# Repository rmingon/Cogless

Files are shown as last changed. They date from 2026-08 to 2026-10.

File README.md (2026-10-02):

<h1 align="center">Cogless</h1>

<p align="center">
  <strong>A single-chip, open-source brushless ESC built around the WCH CH32M007.</strong><br>
  One RISC-V motor-control SoC, six MOSFETs, a handful of passives. Every design file public.
</p>

<p align="center">
  
  
  
  
  
  
  
</p>

<p align="center">
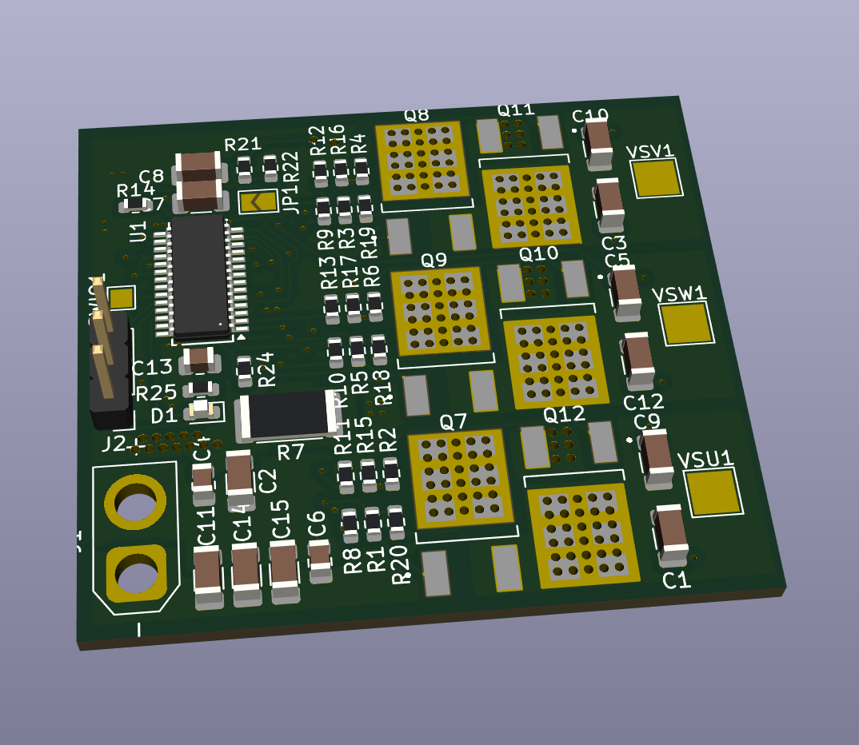
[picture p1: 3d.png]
Cogless 3D render
  
</p>

---

## Overview

Most hobby ESCs are black boxes: closed firmware, undocumented hardware, and a microcontroller, gate driver and op-amps spread over a dozen chips. Cogless takes the opposite approach.

The **WCH CH32M007G8R6** integrates on a single die everything the brain of an ESC needs: a RISC-V core, a three-phase 48 V N+N gate pre-driver with bootstrap diodes, the high-voltage and logic regulators, a programmable-gain current amplifier, comparators wired to the PWM timer's emergency brake, and a 3 Msps ADC. The result is a complete motor controller with **one IC, six MOSFETs and a few passives** on a 45 × 40 mm board.

| | |
|---|---|
| **Control** | Sensorless six-step (trapezoidal) commutation, back-EMF sensing |
| **Start-up** | Automatic motor detection and tuning, stored in flash |
| **Protection** | Hardware over-current break, cycle-by-cycle current limit, voltage and thermal derating |
| **Openness** | KiCad sources, fabrication outputs and firmware, dual-licensed |

## Hardware

### Specifications

| Parameter | Value |
|---|---|
| Controller | WCH CH32M007G8R6, QingKe RISC-V, 48 MHz, 62 KB flash, 8 KB RAM, SSOP-28 |
| Gate driver | Integrated three-phase N+N pre-driver, bootstrap diodes, up to 48 V |
| Power stage | 6 × AOD514 (30 V, 46 A, 5.9 mΩ), DPAK, thermal via arrays |
| Supply | 2S to 4S LiPo (6 V to 16.8 V), XT30 connector |
| Regulation | Internal high-voltage LDO and 5 V logic LDO, no external regulator |
| Current sense | 2 mΩ 2512 shunt, Kelvin-routed differential pair, internal PGA (× 16) |
| Voltage sense | Three phase back-EMF dividers and one battery divider, 33 kΩ / 8.2 kΩ (≈ 25 V full scale) |
| Temperature | 10 kΩ B3500 NTC (Cantherm CMFA103J3500HANT) against the low-side MOSFETs |
| Control input | 3-pin header (5 V, GND, signal) |
| Debug | WCH 1-wire SDI (SWIO pad), WCH-LinkE |
| Indicator | Status LED |
| Board | 4 layers, 45 × 40 mm, KiCad 10 |

<p align="center">
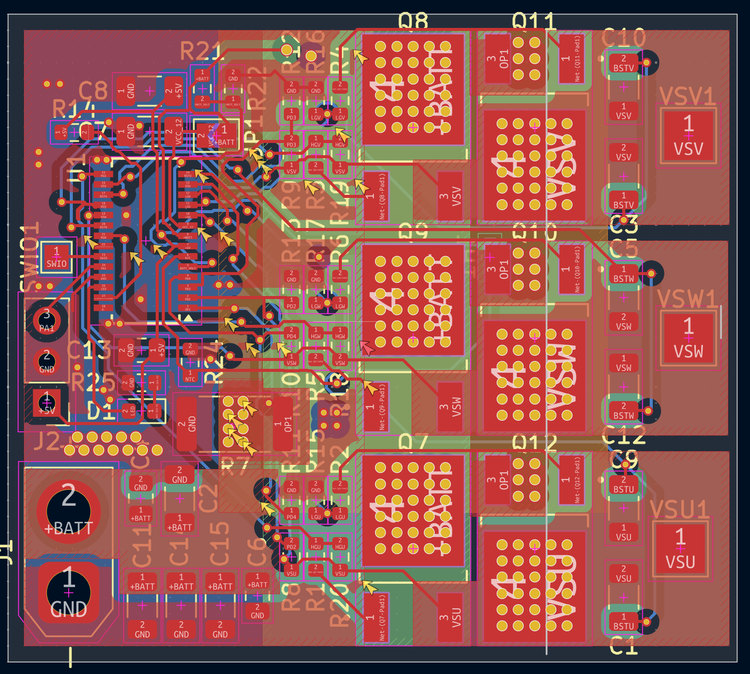
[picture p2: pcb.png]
PCB layout
  
</p>

### Design notes

| Topic | Choice |
|---|---|
| **Current sensing** | The shunt is read differentially: both PGA inputs run as a Kelvin pair straight from the shunt pads, so gate-drive noise and power-trace drops stay out of the measurement. |
| **Hardware over-current** | The PGA output feeds an internal comparator wired to the timer's break input: the bridge shuts down without any software involvement. |
| **Gate safety** | All six MOSFETs have 100 kΩ gate pull-downs, the high sides referenced to their own phase node, so the bridge stays off while the driver powers up. |
| **Sensorless and encoder-ready** | The three phase dividers feed the ADC for back-EMF detection. The control header lands on an ADC and timer-capable pin, ready for an AS5600 or MT6701 encoder. |
| **Supply jumper JP1** | Shorts VHV to VCC12V and bypasses the internal high-voltage regulator, which needs more than 18 V. **JP1 must stay closed for every supported pack, 2S to 4S.** It is bridged by default. |

### Schematic

<p align="center">
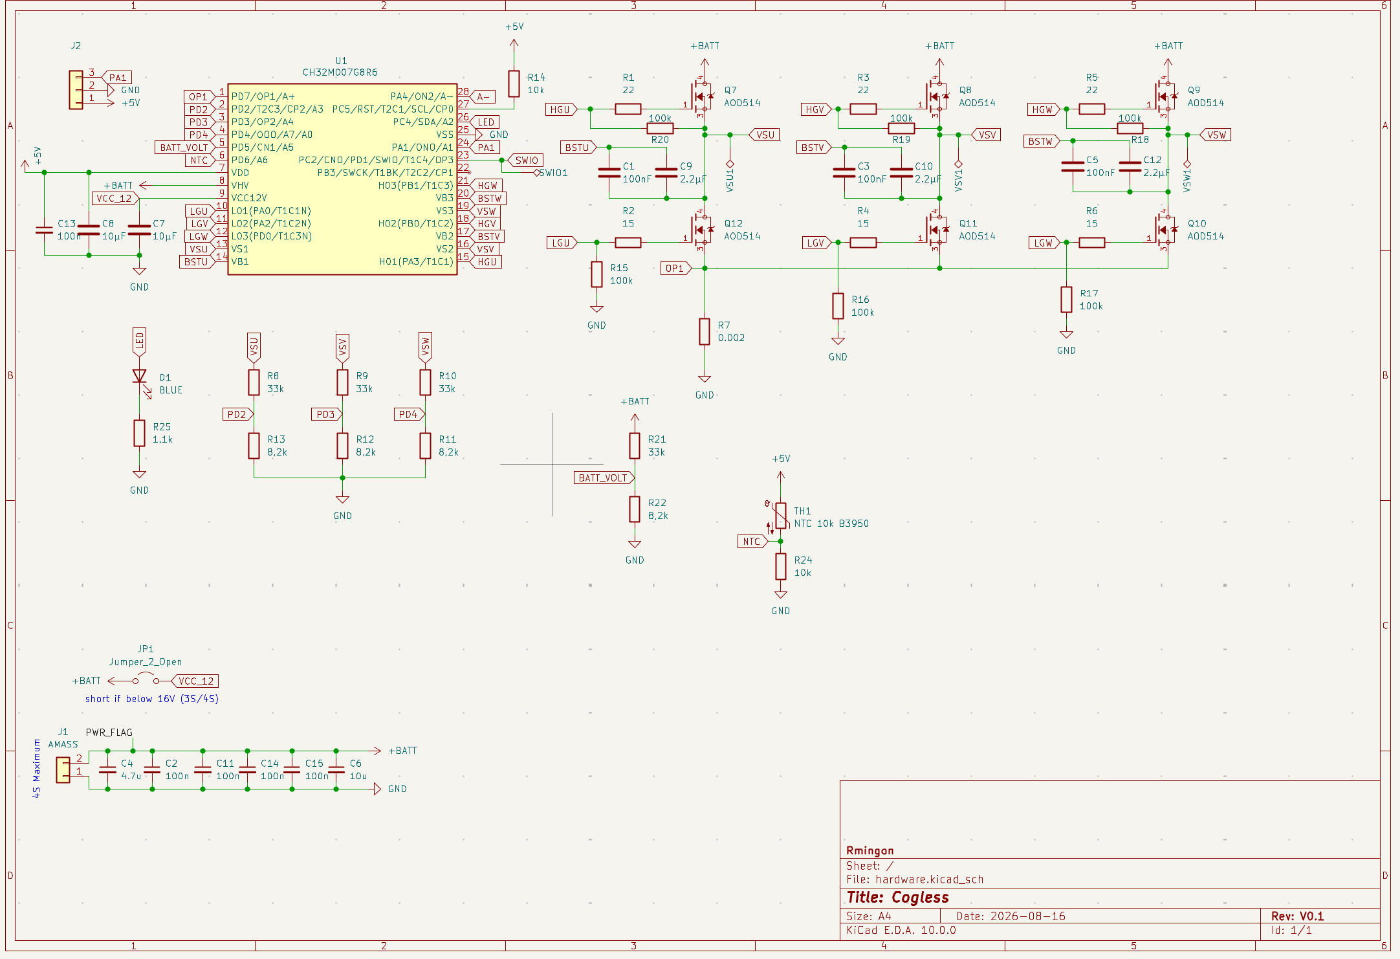
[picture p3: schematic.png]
Schematic
  
</p>

The full KiCad project (schematic, routed board) and the fabrication outputs (BOM, placement, netlist, Gerber archive) are in [`hardware/`](hardware/).

## Firmware

The firmware lives in [`firmware_DShot/`](firmware_DShot/) as a MounRiver Studio 2 project, with its own [README](firmware_DShot/README.md) covering the internals, the test modes and the bring-up notes.

### Features

| Feature | Description | Status |
|---|---|---|
| Six-step sensorless control | 48 kHz centre-aligned PWM, 400 ns dead time, closed loop on back-EMF zero crossings | Validated at 24 kHz, 48 kHz bench pending |
| Back-EMF sensing | Floating phase sampled in the PWM off-time, against ground | Validated |
| Current sensing | Single shunt, differential PGA, sampled inside the high-side pulse | Validated |
| Motor auto-tune | Start current, noise floor, open-loop acceleration, hand-off speed, closed-loop acceleration | Validated |
| Start-up and arming tones | The motor itself is used as a speaker | Validated |
| Servo PWM input | 1000 to 2000 µs on the control header | Implemented, bench validation pending |
| Load test | Power stage under a real propeller or vehicle load | In progress |
| DShot input, telemetry | Digital throttle protocol | Planned |
| Field-oriented control | Sinusoidal drive from the same hardware | Planned |

### Protections

| Protection | Behaviour |
|---|---|
| Hardware over-current | Comparator to timer break, outputs off immediately |
| Software over-current | Fault after three consecutive samples above the limit |
| Current limiting | Cycle-by-cycle peak limit and slow fold-back |
| Speed ceiling | Duty backed off at the highest speed the sampling can follow |
| Under-voltage | Cell count detected at arming, fold-back then cut-off per cell |
| Over-temperature | Board temperature read every 100 ms, derating from 80 °C, cut-off at 100 °C |
| Loss of signal | Throttle failsafe after 100 ms without a valid pulse |
| Desynchronisation and stall | Outputs off, automatic restart at zero throttle |
| Watchdog | Independent watchdog, 100 ms |

### Current limitations

| Limitation | Detail |
|---|---|
| Speed ceiling | About 80 000 eRPM at 48 kHz (≈ 11 400 rpm on a 14-pole motor), duty limited to about 83 % |
| Load validation | Full-power behaviour under a propeller is still being characterised |

## Getting started

| Step | Action |
|---|---|
| 1 | Order the board from the files in [`hardware/production/`](hardware/production/), or build it from the KiCad sources. |
| 2 | Check that **JP1 is closed**. |
| 3 | Open [`firmware_DShot/`](firmware_DShot/) in MounRiver Studio 2, build, and flash through a WCH-LinkE on SWIO, GND and 5 V. |
| 4 | First power-up on a current-limited supply, motor fixed, **no propeller**. The ESC beeps, then tunes itself to the motor. |
| 5 | Set the throttle source and limits in [`motor_config.h`](firmware_DShot/User/motor_config.h). |

## Repository layout

| Path | Content |
|---|---|
| [`hardware/`](hardware/) | KiCad 10 project: schematic, PCB |
| [`hardware/production/`](hardware/production/) | Fabrication outputs: BOM, placement, netlist, Gerber archive |
| [`firmware_DShot/`](firmware_DShot/) | Firmware, MounRiver Studio 2 project |
| [`firmware_DShot/User/`](firmware_DShot/User/) | Cogless firmware sources |
| [`LICENSE-HARDWARE`](LICENSE-HARDWARE) | CERN-OHL-S v2 |
| [`LICENSE-FIRMWARE`](LICENSE-FIRMWARE) | GPL-3.0 |
| [`LICENSE-COMMERCIAL.md`](LICENSE-COMMERCIAL.md) | Commercial licensing |

The CH32M007 datasheet and reference manual are available from [WCH](https://www.wch-ic.com/products/CH32M007.html).

## Safety

> **Warning.** This is a power-electronics project. LiPo batteries and spinning motors can cause fire and serious injury. Always start on a current-limited supply, keep propellers off during bring-up and auto-tune, and never leave a first power-up unattended. You build and use this design at your own risk.

## Contributing

Issues and pull requests are welcome: layout review, firmware improvements, bring-up reports, or photos of your build. If you spin a variant (higher-voltage MOSFETs, other connectors), open a discussion first: the goal is a family of small, hackable ESCs.

Because Cogless is dual-licensed, a contribution can only be merged if you agree that it may also be distributed under the commercial licence. You keep the copyright of your contribution.

## License

Cogless is **dual-licensed**: open source under strong copyleft licences, or under a commercial licence.

| Part | Open-source licence |
|---|---|
| **Hardware**: everything under [`hardware/`](hardware/) | [CERN-OHL-S v2](LICENSE-HARDWARE) |
| **Firmware**: the files written for Cogless, marked with the Cogless SPDX header | [GPL-3.0-only](LICENSE-FIRMWARE) |

| You want to | Licence |
|---|---|
| Use, study, modify, build or sell Cogless, and publish your modified design files and firmware under the same licences | Open source, free of charge |
| Ship a product based on Cogless without publishing your changes, or combine the firmware with proprietary code | [Commercial licence](LICENSE-COMMERCIAL.md) |

**Third-party files.** The WCH SDK files in `firmware_DShot/Core/`, `Peripheral/`, `Startup/`, `Debug/`, and the `system_ch32v00X.*`, `ch32v00X_it.*` and `ch32v00X_conf.h` files in `User/`, are copyright Nanjing Qinheng Microelectronics (WCH) and remain under WCH's own terms. They are not covered by the Cogless licences.

<p align="center"><sub>Copyright © 2026 Ronan Mingon</sub></p>

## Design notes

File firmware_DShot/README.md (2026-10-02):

# Cogless firmware (CH32M007G8R6)

Sensorless six-step (trapezoidal) BLDC controller for the Cogless ESC. MounRiver Studio 2 project, WCH CH32V00X peripheral library.

## Files

| File | Role |
|---|---|
| `User/board.h` | Pin map and scaling constants, derived from `hardware/hardware.kicad_sch` |
| `User/motor_config.h` | Tunables: PWM frequency, dead time, start ramp, current and voltage limits |
| `User/motor.c` | 48 kHz control loop: TIM1 PWM to the internal gate driver, PGA current sense, BEMF zero-crossing commutation, protections |
| `User/rc_input.c` | Servo PWM throttle capture on J2.3 (EXTI on PA1, TIM2 as time base) |
| `User/telemetry.c` | Text telemetry over the SDI debug wire, non-blocking |
| `User/motor_tune.c` | Motor auto-detection, start-up adaptation, flash storage |
| `User/main.c` | 1 ms scheduler: arming, derating, LED, watchdog |

## Pin usage

| MCU pin | Function | Firmware |
|---|---|---|
| PA3, PB0, PB1 | HO1..3 (TIM1 CH1..3, remap 0100b) | High-side gates U, V, W |
| PA0, PA2, PD0 | LO1..3 (TIM1 CH1N..3N) | Low-side gates, complementary with 1 us dead time |
| PD7 / PA4 | OPA_P1 / OPA_N2 | Shunt, differential PGA x16, VDD/2 bias |
| PD2, PD3, PD4 | ADC_IN3, IN4, IN7 | Phase U, V, W back-EMF dividers |
| PD5 | ADC_IN5 | Battery voltage |
| PD6 | ADC_IN6 | NTC (Cantherm CMFA103J3500HANT, 10k B3500) |
| PA1 | EXTI1 + TIM2 free counter | Servo PWM input, 1000..2000 us (TIM2 remaps 5/6 would steal PA0/PA2/PA3 from TIM1) |
| PC4 | GPIO | Status LED |
| PC2 | SWIO | WCH-LinkE, also carries telemetry |

## Status

Validated on the bench on 2026-09-30 with a 1503 motor on 3S: open-loop start, hand-off to sensorless closed loop, stable run around 3 500 rpm (10 % duty). Current sensing, hardware over-current break and software limits are active.

## How it works

Each PWM period (48 kHz, centre-aligned) TIM1 CH4 starts an ADC injected sequence inside the high-side ON pulse: PGA output (current), floating-phase voltage, bus voltage. The floating phase is also sampled in the middle of the OFF time, where it reads 1.5 times its back-EMF against ground; that sample drives the zero-crossing detector. The loop applies blanking after each commutation and commutates 30 degrees (minus a small advance) after the crossing. When the first samples show the crossing already passed, the crossing is dated at the detection, so a rotor running ahead is caught up. Startup: bootstrap precharge (all low-side on), alignment, then an open-loop ramp until six consecutive zero crossings land in the middle of the forced steps.

Protections:

- Hardware over-current: PGA output into CMP2 into the TIM1 break input, about 66 A, no software involved.
- Software over-current at 45 A (3 samples), current fold-back above 30 A.
- Desync (no zero crossing for 60 ms or 4 periods) and stall (ramp timeout): outputs off, automatic retry after 500 ms at zero throttle.
- Under-voltage: fold-back below 3.3 V/cell, stop below 3.0 V/cell. Cell count detected at arming (2S, 3S, 4S).
- Over-temperature: fold-back above 80 C, stop at 100 C. The NTC is read every 100 ms, also while the motor runs.
- RC failsafe: no pulse for 100 ms stops the motor and disarms.
- Independent watchdog, 100 ms.

## Arming and LED

1. Power on with the throttle at minimum. The LED gives one long blink (500 ms) every 2 s while no RC signal is seen, a slow blink (1 s on, 1 s off) while waiting.
2. Hold zero throttle for 1 s: LED solid, armed.
3. Throttle up: LED blinks at 4 Hz while running.
4. Fault: the LED blinks the fault code, then pauses. 1 hardware over-current, 2 software over-current, 3 desync, 4 stall, 5 under-voltage, 6 over-temperature, 7 control-loop overrun.

## Telemetry

Connect a WCH-LinkE and open the SDI printf console in MounRiver (or `wlink`). A line is printed every 200 ms:

```
st=4 f=0 arm=1 rc=1500 thr=500 duty=520 erpm=24000 I=6200mA V=15800mV 4S T=41C
```

Without a debugger the writer times out on the first packet and stays silent, so the control loop is never blocked.

## First bring-up checklist

1. JP1 must be closed for every supported pack (the internal regulator needs more than 18 V, see the datasheet), whatever the silkscreen says.
2. Use a current-limited supply, no propeller.
3. Check with a scope that the LO/HO outputs show complementary PWM with dead time on `motor_start()`.
4. If the motor twitches and stops with fault 4 (stall), tune `RAMP_DUTY_*` and `RAMP_*_STEP_US` in `motor_config.h` for the motor. Small high-KV motors need shorter steps; large motors need more duty.
5. Direction: build with `-DMOTOR_REVERSE=1` or swap two motor wires.

## Motor auto-detection (`User/motor_tune.c`)

At power-up, when no result is stored in flash (`AUTOTUNE_MODE 1`), the controller characterises the motor, **which must turn freely, without propeller**:

1. **Standstill sweep** on one step: the duty that gives `TUNE_I_TARGET_MA`, and a phase-to-phase resistance estimate.
2. **Parasitic floor**: the floating-phase reading in the PWM OFF time with that current flowing.
3. **Open-loop acceleration** at regulated current, 20 to 670 steps/s. The BEMF peak is recorded at every step. Synchronism is checked with peak x period, which stays constant while the rotor follows. Loss of sync triggers a retry with a gentler ramp, then with 1.5 x the current (6 attempts).
4. **Hand-off speed**: where the BEMF peak reaches 4 x the floor (at least 40 LSB).
5. **Storage** in the last 256 B of flash (0x0800F700, excluded in `Ld/Link.ld`). The result is reloaded at every power-up.

LED: fast blinking during the tune, three long blinks when done. If the tune fails, the LED blinks the error code twice (3 = no motor, 4 = over-current, 5 = no synchronism, 6 = flash) and the defaults stay in use. The details are in `tune_res` (debugger). Reflashing the firmware usually erases the record, so the tune runs again. `AUTOTUNE_MODE 2` forces a tune at every power-up.

## Bring-up findings (keep these)

- **TIM2 remap for the RC input breaks the gate driver.** Remaps 5/6 put TIM2 channels on PA0/PA2/PA3 and steal them from TIM1. The RC input uses EXTI on PA1 instead.
- **Off phases must keep their driver inputs driven.** With CCxE = CCxNE = 0, TIM1 releases both pins and the CH283 inputs float. Off phases use CCxE = 1 with the output forced inactive.
- **OCxN only follows OCxREF on an edge.** Switching a channel straight to "forced inactive" can leave its low side off. `apply_regs()` inserts a pulse shorter than the dead time to create the edge.
- **The shunt only carries current during the high-side pulse.** It is sampled first in the ADC sequence, right at the centre of the pulse.
- **Never disable the CMP2 break.** Its trips were real current; a 1503 burned while it was off.
- **The ADC sample time is per channel.** U and V BEMF channels left at reset kept ~9 % of the previous conversion (160 LSB on a phase at 0 V). Every channel is now set explicitly, and the ADC leaves low-power mode.
- **The BEMF is read in the PWM OFF time** (TIM1 update at the top of the count). The two driven phases are at 0 V, so there is no neutral to estimate.
- **Unloaded open loop leaves the rotor ahead of the commutation.** The zero crossing happens before the step starts, so an "already crossed" first sample is accepted at the end of the ramp, with the closed-loop acceleration limited per step.

## Bring-up switches (`motor_config.h`)

| Switch | Use |
|---|---|
| `TEST_AUTORUN 1` | runs without RC: arm, 10 s ON, 3 s OFF, forever. Set to 0 for RC control |
| `MOTOR_TEST_OPEN_LOOP 1` | forced six-step only, no sensorless hand-off |
| `DRIVER_PIN_TEST 1..6` | static probes of the gate driver, the PGA path and each phase; 0 for normal firmware |
| `motor_trace[]` | last 96 commutations: period, duty, current, zero-crossing position, BEMF extremes, faults |

## Limits of this version

- Zero crossings are sampled once per PWM period and the step is capped at 6 ticks, so the electrical speed is limited to about 80 000 eRPM at 48 kHz (about 11 400 rpm on a 14-pole motor). A proportional duty cap holds the speed just under that ceiling. At 48 kHz the OFF-time sample limits the duty to about 83 %.
- Servo PWM input only. DShot and the analog encoder input on PA1 are not implemented.
- No FOC yet: this is the six-step baseline to validate the hardware.

## Building outside MounRiver

The toolchain shipped with MounRiver Studio 2 works from the command line:

```
GCC="/Applications/MounRiver Studio 2.app/Contents/Resources/app/resources/darwin/components/WCH/Toolchain/RISC-V Embedded GCC12/bin/riscv-wch-elf-gcc"
CF="-march=rv32ec_zmmul -mabi=ilp32e -msmall-data-limit=8 -mno-save-restore -Os -fsigned-char -ffunction-sections -fdata-sections -fno-common -IStartup -IDebug -ICore -IUser -IPeripheral/inc"
for f in User/*.c Debug/*.c Core/*.c Peripheral/src/*.c; do "$GCC" $CF -c $f -o build/$(basename ${f%.c}).o; done
"$GCC" $CF -x assembler-with-cpp -c Startup/startup_ch32v00X.S -o build/startup.o
"$GCC" $CF -T Ld/Link.ld -nostartfiles -Xlinker --gc-sections --specs=nano.specs --specs=nosys.specs build/*.o -o build/fw.elf
```

## License

The firmware files written for Cogless (`User/` files with the Cogless SPDX header) are dual-licensed: [GPL-3.0-only](../LICENSE-FIRMWARE) or a commercial licence ([LICENSE-COMMERCIAL.md](../LICENSE-COMMERCIAL.md)). The WCH SDK files keep WCH's own terms. See the [root README](../README.md#license).

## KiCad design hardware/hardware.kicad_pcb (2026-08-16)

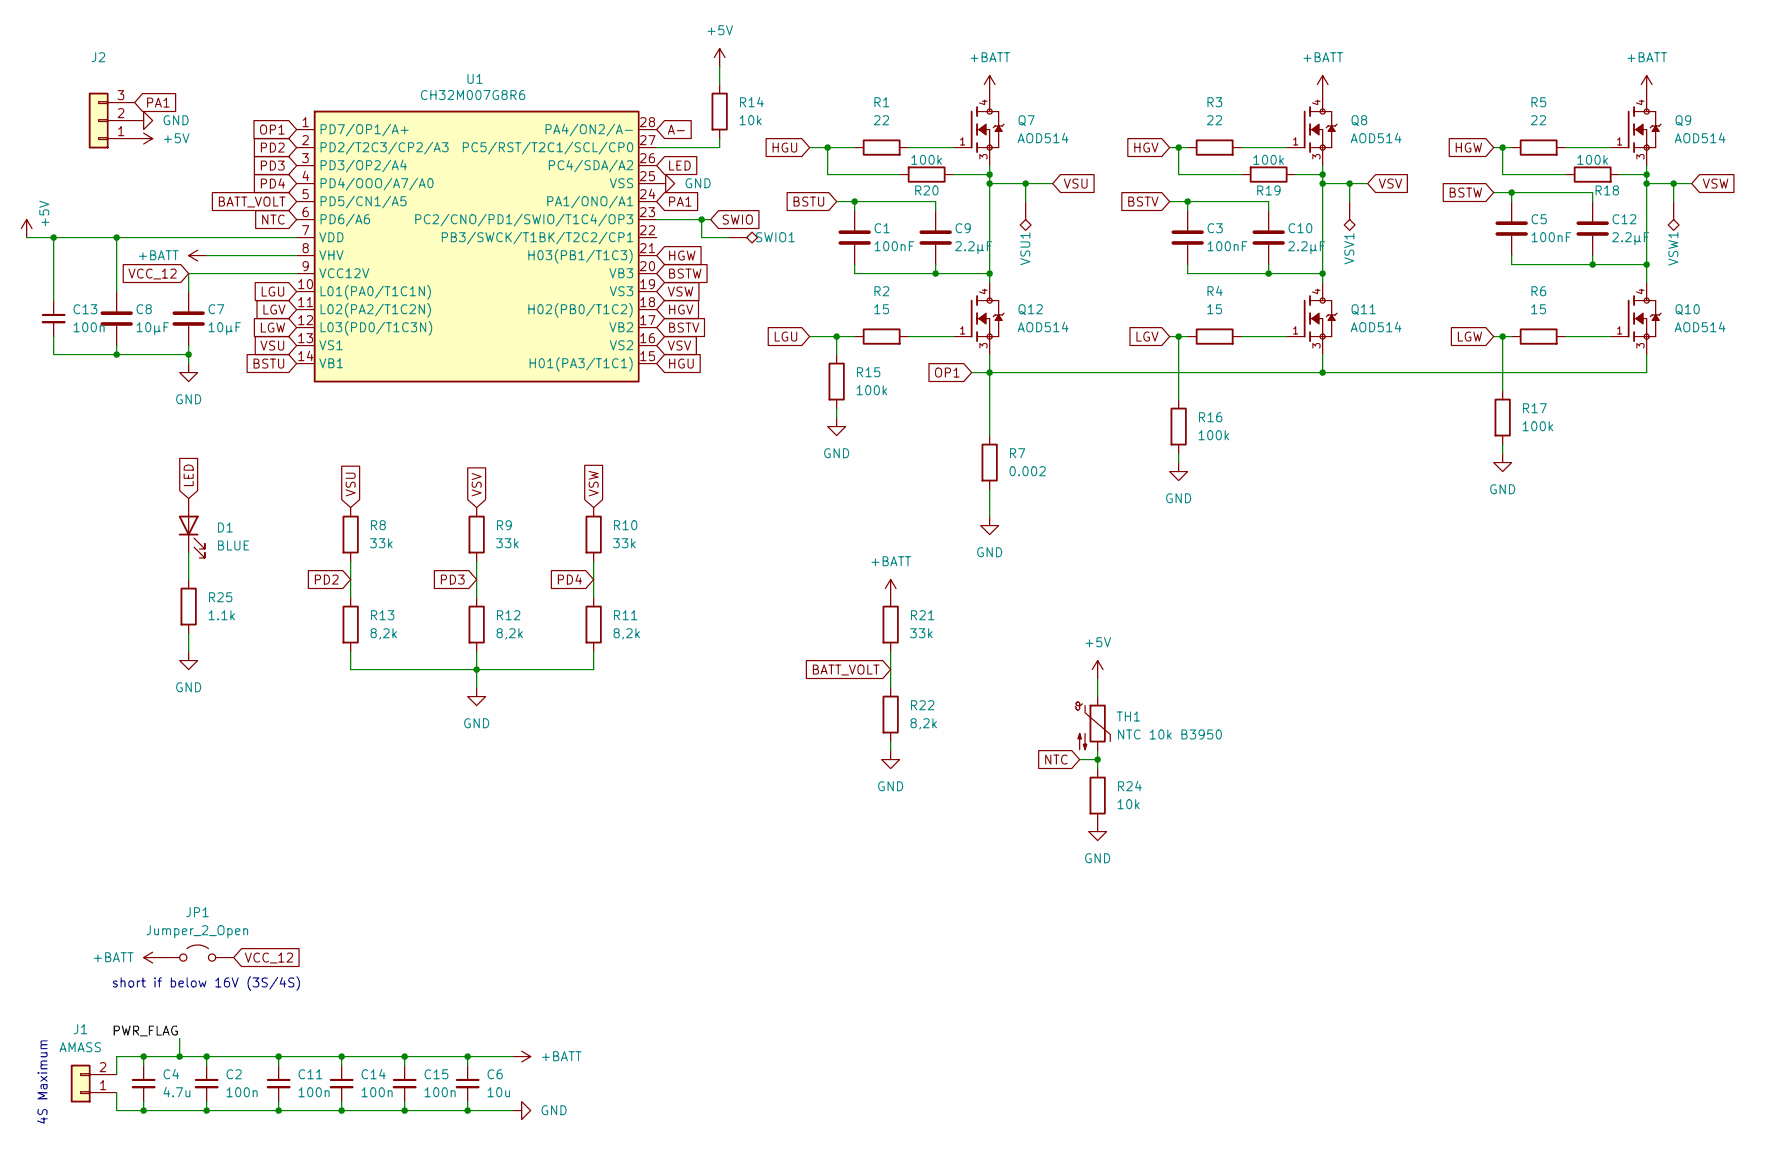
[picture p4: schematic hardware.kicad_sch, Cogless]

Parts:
C1, C3, C5: 100nF; C_1206_3216Metric
C2, C11, C14, C15: 100n; C_1206_3216Metric
C4: 4.7u; C_0805_2012Metric
C6: 10u; C_0805_2012Metric
C7, C8: 10µF; C_1206_3216Metric
C9, C10, C12: 2.2µF; C_1206_3216Metric
C13: 100n; C_0805_2012Metric
D1: BLUE; LED_0603_1608Metric
J1: AMASS; AMASS_XT30U-F_1x02_P5.0mm_Vertical
J2: Conn_01x03; PinHeader_1x03_P2.54mm_Vertical
JP1: Jumper_2_Open; SolderJumper-2_P1.3mm_Open_TrianglePad1.0x1.5mm
Q7, Q8, Q9, Q10, Q11, Q12: AOD514; TRANS_AOD514; PARTREV V
R1, R3, R5: 22; R_0603_1608Metric
R2, R4, R6: 15; R_0603_1608Metric
R7: 0.002; R_2512_6332Metric
R8, R9, R10, R21: 33k; R_0603_1608Metric
R11, R12, R13, R22: 8,2k; R_0603_1608Metric
R14, R24: 10k; R_0603_1608Metric
R15, R16, R17, R18, R19, R20: 100k; R_0603_1608Metric
R25: 1.1k; R_0603_1608Metric
SWIO1: TestPoint_Alt; TestPoint_Pad_1.5x1.5mm
TH1: NTC 10k B3950; C_0603_1608Metric
U1: CH32M007G8R6; SSOP-28_3.9x9.9mm_P0.635mm
VSU1: TestPoint_Alt; TestPoint_Pad_3.0x3.0mm
VSV1: TestPoint_Alt; TestPoint_Pad_3.0x3.0mm
VSW1: TestPoint_Alt; TestPoint_Pad_3.0x3.0mm

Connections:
+5V: C8.2, C13.1, J2.1, R14.1, TH1.1, U1.7 (VDD)
+BATT: C2.1, C4.1, C6.1, C11.1, C14.1, C15.1, J1.2, JP1.1 (A), Q7.4, Q8.4, Q9.4, R21.1, U1.8 (VHV)
A-: U1.28 (PA4/ON2/A-)
BATT_VOLT: R21.2, R22.1, U1.5 (PD5/CN1/A5)
BSTU: C1.1, C9.2, U1.14 (VB1)
BSTV: C3.1, C10.2, U1.17 (VB2)
BSTW: C5.1, C12.2, U1.20 (VB3)
GND: C2.2, C4.2, C6.2, C7.1, C8.1, C11.2, C13.2, C14.2, C15.2, J1.1, J2.2, R7.2, R11.2, R12.2, R13.2, R15.2, R16.2, R17.2, R22.2, R24.2, R25.2, U1.25 (VSS)
HGU: R1.1, R20.2, U1.15 (H01(PA3/T1C1))
HGV: R3.1, R19.2, U1.18 (H02(PB0/T1C2))
HGW: R5.1, R18.1, U1.21 (H03(PB1/T1C3))
LED: D1.2 (A), U1.26 (PC4/SDA/A2)
LGU: R2.1, R15.1, U1.10 (L01(PA0/T1C1N))
LGV: R4.1, R16.1, U1.11 (L02(PA2/T1C2N))
LGW: R6.1, R17.1, U1.12 (L03(PD0/T1C3N))
NTC: R24.1, TH1.2, U1.6 (PD6/A6)
unnamed: D1.1 (K), R25.1
unnamed: Q7.1, R1.2
unnamed: Q8.1, R3.2
unnamed: Q9.1, R5.2
unnamed: Q10.1, R6.2
unnamed: Q11.1, R4.2
unnamed: Q12.1, R2.2
unnamed: R14.2, U1.27 (PC5/RST/T2C1/SCL/CP0)
OP1: Q10.3, Q11.3, Q12.3, R7.1, U1.1 (PD7/OP1/A+)
PA1: J2.3, U1.24 (PA1/ONO/A1)
PD2: R8.2, R13.1, U1.2 (PD2/T2C3/CP2/A3)
PD3: R9.2, R12.1, U1.3 (PD3/OP2/A4)
PD4: R10.2, R11.1, U1.4 (PD4/OOO/A7/A0)
SWIO: SWIO1.1 (1_1), U1.23 (PC2/CNO/PD1/SWIO/T1C4/OP3)
VCC_12: C7.2, JP1.2 (B), U1.9 (VCC12V)
VSU: C1.2, C9.1, Q7.3, Q12.4, R8.1, R20.1, U1.13 (VS1), VSU1.1 (1_1)
VSV: C3.2, C10.1, Q8.3, Q11.4, R9.1, R19.1, U1.16 (VS2), VSV1.1 (1_1)
VSW: C5.2, C12.1, Q9.3, Q10.4, R10.1, R18.2, U1.19 (VS3), VSW1.1 (1_1)

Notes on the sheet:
4S Maximum
short if below 16V (3S/4S)

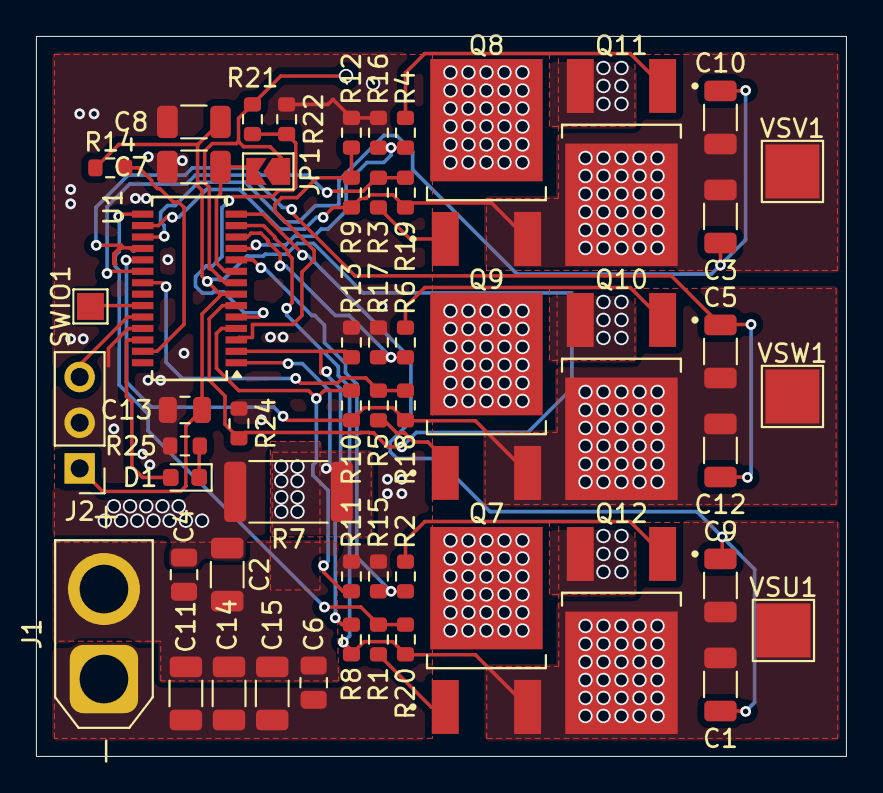
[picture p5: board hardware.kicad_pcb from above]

Board: 4 copper layers, 45.0 x 40.0 mm, 55 parts (1 on the bottom side), 33 nets.

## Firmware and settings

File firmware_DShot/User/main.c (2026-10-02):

/* SPDX-License-Identifier: GPL-3.0-only OR LicenseRef-Cogless-Commercial
 * Copyright (c) 2026 Ronan Mingon */
/*
 * main.c - Cogless ESC firmware (CH32M007G8R6, integrated 3-phase gate
 * driver): sensorless six-step BLDC control.
 *
 *   board.h        pin map and hardware scaling
 *   motor_config.h tunables: PWM, start-up, limits, test modes
 *   motor.c        48 kHz control loop: PWM, current sense, BEMF commutation
 *   motor_tune.c   motor auto-detection, start-up parameters in flash
 *   rc_input.c     servo PWM throttle on J2 (PA1)
 *   telemetry.c    SDI text output (safe without a debugger)
 *
 * Power-up: beeps, auto-tune if no result is stored, then the 1 ms loop:
 * arming, voltage and temperature derating, LED, telemetry, watchdog.
 * Arming: valid throttle at minimum for 1 s (or TEST_AUTORUN), battery present.
 * Desync and stall retry after 500 ms at zero throttle; the other faults
 * need the throttle held low again.
 */

#include <string.h>
#include "debug.h"
#include "board.h"
#include "motor.h"
#include "motor_config.h"
#include "rc_input.h"
#include "telemetry.h"
#include "motor_tune.h"

#ifndef MOTOR_REVERSE
#define MOTOR_REVERSE        0
#endif

#define HARD_FAULT_CLEAR_MS  2000U
#define TELEMETRY_PERIOD_MS  200U
#define NTC_PERIOD_MS        100U
#define LED_SLOT_MS          125U      /* 16 slots = 2 s pattern */

/* ------------------------------------------------------------------ LED */
static void led_init(void)
{
    GPIO_InitTypeDef g = {0};

    RCC_PB2PeriphClockCmd(RCC_PB2Periph_GPIOC, ENABLE);
    g.GPIO_Pin   = BOARD_LED_PIN;
    g.GPIO_Mode  = GPIO_Mode_Out_PP;
    g.GPIO_Speed = GPIO_Speed_30MHz;
    GPIO_Init(BOARD_LED_PORT, &g);
}

void led_set(uint8_t on)
{
    if (on) GPIO_SetBits(BOARD_LED_PORT, BOARD_LED_PIN);
    else    GPIO_ResetBits(BOARD_LED_PORT, BOARD_LED_PIN);
}

/* 16-bit pattern, one bit per 125 ms, MSB first */
static uint16_t led_pattern(uint8_t armed, uint8_t rc_ok, motor_state_t st, motor_fault_t f)
{
    if (st == MOTOR_FAULT)
    {
        /* f SHORT (125 ms) blinks then a pause: 1010..00 */
        uint16_t p = 0;
        uint8_t i;
        for (i = 0; i < f && i < 7; i++)
        {
            p |= (uint16_t)(0x8000U >> (2U * i));
        }
        return p;
    }
    if (!rc_ok)  return 0xF000;                 /* one LONG (500 ms) blink per 2 s */
    if (!armed)  return 0xFF00;                 /* slow blink, 1 s on / 1 s off   */
    if (st == MOTOR_STOPPED || st == MOTOR_BRAKE) return 0xFFFF; /* solid */
    return 0xAAAA;                              /* running: 4 Hz            */
}

/* ---------------------------------------------------------------- beeps */
/* { frequency Hz (0 = silence), duration ms } */
typedef struct { uint16_t f; uint16_t ms; } note_t;

static const note_t mel_power[]   = { {1046, 120}, {0, 40}, {1318, 120}, {0, 40}, {1568, 180} };
static const note_t mel_tune[]    = { {1568, 80}, {0, 80}, {1568, 80} };
static const note_t mel_tune_ok[] = { {1318, 120}, {0, 40}, {2093, 220} };
static const note_t mel_fail[]    = { {523, 600} };
static const note_t mel_armed[]   = { {1568, 300} };

static void play(const note_t *mel, uint8_t n)
{
#if BEEP_ENABLE
    uint8_t i;
    for (i = 0; i < n; i++)
    {
        if (mel[i].f == 0U)
        {
            Delay_Ms(mel[i].ms);
            continue;
        }
        motor_beep(mel[i].f, mel[i].ms, BEEP_DUTY_PM);
        while (motor_beep_busy())
        {
            IWDG_ReloadCounter();          /* harmless before the watchdog is on */
        }
    }
#else
    (void)mel; (void)n;
#endif
}
#define PLAY(m) play((m), (uint8_t)(sizeof(m) / sizeof((m)[0])))

/* ------------------------------------------------------------------ NTC */
#if NTC_PRESENT
volatile int16_t board_temp_c = 25;   /* last NTC reading, for the debugger */

static int16_t ntc_to_celsius(uint16_t adc)
{
    static const uint16_t tab[] = BOARD_NTC_TABLE;
    const uint8_t n = sizeof(tab) / sizeof(tab[0]);
    uint8_t i;

    if (adc <= tab[0])     return BOARD_NTC_TABLE_T_MIN_C;
    if (adc >= tab[n - 1]) return (int16_t)(BOARD_NTC_TABLE_T_MIN_C + (n - 1) * BOARD_NTC_TABLE_STEP_C);
    for (i = 0; i < n - 1; i++)
    {
        if (adc < tab[i + 1])
        {
            uint16_t span = tab[i + 1] - tab[i];
            return (int16_t)(BOARD_NTC_TABLE_T_MIN_C + i * BOARD_NTC_TABLE_STEP_C
                             + ((uint32_t)(adc - tab[i]) * BOARD_NTC_TABLE_STEP_C) / span);
        }
    }
    return 0;
}
#endif

/* -------------------------------------------------------------- watchdog */
static void iwdg_init(void)
{
    IWDG_WriteAccessCmd(IWDG_WriteAccess_Enable);
    IWDG_SetPrescaler(IWDG_Prescaler_32);      /* 128 kHz / 32 = 4 kHz */
    IWDG_SetReload(400);                       /* 100 ms               */
    IWDG_ReloadCounter();
    IWDG_Enable();
}

/* ------------------------------------------------------------ telemetry */
static void telemetry_line(uint8_t armed, uint8_t cells, int16_t temp_c)
{
    tel_puts("st=");   tel_put_uint(motor_state());
    tel_puts(" f=");   tel_put_uint(motor_fault());
    tel_puts(" arm="); tel_put_uint(armed);
    tel_puts(" rc=");  tel_put_uint(rc_pulse_us());
    tel_puts(" thr="); tel_put_uint(motor_throttle());
    tel_puts(" duty=");tel_put_uint(motor_duty());
    tel_puts(" erpm=");tel_put_uint(motor_erpm());
    tel_puts(" I=");   tel_put_int(motor_current_ma());
    tel_puts("mA V="); tel_put_uint(motor_vbus_mv());
    tel_puts("mV ");   tel_put_uint(cells);
    tel_puts("S T=");  tel_put_int(temp_c);
    tel_puts("C\r\n");
}

/* --------------------------------------------------------- driver probe */
#if DRIVER_PIN_TEST == 6
volatile uint8_t  lsreg_step;          /* 1..4, step being shown */
volatile uint16_t lsreg_ccer, lsreg_chctlr1, lsreg_chctlr2, lsreg_bdtr, lsreg_ctlr2;
volatile uint32_t lsreg_afio_pcfr1, lsreg_gpioa_cfglr, lsreg_gpiod_cfglr;

static void ls_tim1_test(void)
{
    static const uint8_t modes[4] = { 1, 8, 9, 10 };
    uint8_t step = 0;

    if (motor_init())
    {
        while (1) { led_set(1); Delay_Ms(50); led_set(0); Delay_Ms(50); }
    }
    while (1)
    {
        uint32_t t = 0;
        uint8_t  i;

        motor_debug_outputs(modes[step], 0);
        lsreg_step        = (uint8_t)(step + 1U);
        lsreg_ccer        = TIM1->CCER;
        lsreg_chctlr1     = TIM1->CHCTLR1;
        lsreg_chctlr2     = TIM1->CHCTLR2;
        lsreg_bdtr        = TIM1->BDTR;
        lsreg_ctlr2       = TIM1->CTLR2;
        lsreg_afio_pcfr1  = AFIO->PCFR1;
        lsreg_gpioa_cfglr = GPIOA->CFGLR;
        lsreg_gpiod_cfglr = GPIOD->CFGLR;
        for (i = 0; i <= step; i++)
        {
            led_set(1); Delay_Ms(100);
            led_set(0); Delay_Ms(200);
            t += 300;
        }
        Delay_Ms(4000U - t);
        step = (uint8_t)((step + 1U) % 4U);
    }
}
#elif DRIVER_PIN_TEST == 5
volatile uint8_t hs_check_phase;       /* 1 = V under test, 2 = W, 3 = done */

static void hs_check_hold(uint8_t mode, uint8_t blink)
{
    uint32_t t;
    motor_debug_outputs(mode, HS_CHECK_DUTY);
    for (t = 0; t < HS_CHECK_MS; t += 125)
    {
        if (motor_state() == MOTOR_FAULT)
        {
            return;
        }
        led_set(blink ? (uint8_t)((t / 125U) & 1U) : 1U);
        Delay_Ms(125);
    }
}

static void hs_check(void)
{
    if (motor_init())
    {
        while (1) { led_set(1); Delay_Ms(50); led_set(0); Delay_Ms(50); }
    }
    Delay_Ms(2000);
    hs_check_phase = 1;
    hs_check_hold((uint8_t)(2U + HS_CHECK_ENTRY_A), 0);
    hs_check_phase = 2;
    hs_check_hold((uint8_t)(2U + HS_CHECK_ENTRY_B), 1);
    hs_check_phase = 3;
    motor_debug_outputs(0, 0);
    while (1)
    {
        led_set(1); Delay_Ms(500);
        led_set(0); Delay_Ms(500);
    }
}
#elif DRIVER_PIN_TEST == 4
volatile int32_t  sweep_ma[SWEEP_POINTS];
volatile uint8_t  sweep_done;          /* number of points completed */
volatile uint8_t  sweep_aborted;
volatile int32_t  sweep_zero;          /* PGA output at zero current, LSB */
volatile uint16_t sweep_vbus_idle;     /* mV, bridge off */
volatile uint16_t sweep_vbus_min[SWEEP_POINTS]; /* lowest bus voltage per point, mV */
volatile uint8_t  sweep_abort_reason;  /* 1 = shunt reading, 2 = bus sag, 3 = fault */

static void current_sweep(void)
{
    static const uint16_t duty[SWEEP_POINTS] = SWEEP_DUTIES;
    uint8_t k;

    if (motor_init())
    {
        while (1) { led_set(1); Delay_Ms(50); led_set(0); Delay_Ms(50); }
    }
    Delay_Ms(2000);                        /* time to stand back */
    {
        uint32_t z = 0;                    /* zero-current baseline, bridge off */
        uint8_t  j;
        for (j = 0; j < 64; j++) { Delay_Ms(1); z += motor_debug_iraw(); }
        sweep_zero = (int32_t)(z / 64U);
        sweep_vbus_idle = motor_vbus_mv();
    }
    for (k = 0; k < SWEEP_POINTS; k++)
    {
        int32_t  sum = 0;
        uint16_t i, n = 0;
        uint16_t vmin = 0xFFFF;

        motor_debug_outputs(2, duty[k]);   /* entry 0: U PWM, V low */
        led_set(1);
        for (i = 0; i < SWEEP_POINT_MS; i++)
        {
            int32_t  ma;
            uint16_t v;
            Delay_Ms(1);
            v = motor_vbus_mv();
            if (v < vmin) vmin = v;
            if (v + SWEEP_ABORT_SAG_MV < sweep_vbus_idle)
            {
                sweep_abort_reason = 2;
                sweep_aborted = 1;
                break;
            }
            if (i < 30)
            {
                continue;                  /* let the current settle */
            }
            ma = ((int32_t)motor_debug_iraw() - sweep_zero)
                 * BOARD_I_MA_PER_LSB_NUM / BOARD_I_MA_PER_LSB_DEN;
            sum += ma;
            n++;
            if (ma > SWEEP_ABORT_MA || motor_state() == MOTOR_FAULT)
            {
                sweep_abort_reason = (motor_state() == MOTOR_FAULT) ? 3 : 1;
                sweep_aborted = 1;
                break;
            }
        }
        sweep_ma[k] = n ? sum / n : 0;
        sweep_vbus_min[k] = vmin;
        sweep_done = (uint8_t)(k + 1U);
        if (sweep_aborted)
        {
            break;
        }
    }
    motor_debug_outputs(0, 0);             /* bridge off for good */
    if (motor_state() == MOTOR_FAULT && !sweep_abort_reason)
    {
        sweep_abort_reason = 3;
    }
    while (1)
    {
        led_set(1); Delay_Ms(500);
        led_set(0); Delay_Ms(500);
    }
}
#elif DRIVER_PIN_TEST == 3
volatile uint16_t pga_probe[4];
volatile uint8_t  pga_probe_done;

static uint16_t pga_probe_read(uint32_t mode1, uint32_t vbsel)
{
    uint32_t sum = 0;
    uint8_t  i;

    OPA_Unlock();
    OPA->CTLR1 = (OPA->CTLR1 & ~((3UL << 1) | (1UL << 17))) | (mode1 << 1) | (vbsel << 17);
    Delay_Ms(20);                          /* settle */
    for (i = 0; i < 64; i++)
    {
        Delay_Ms(1);
        sum += motor_debug_iraw();
    }
    return (uint16_t)(sum / 64U);
}

static void pga_path_test(void)
{
    if (motor_init())                      /* bridge stays off (MOE = 0) */
    {
        while (1) { led_set(1); Delay_Ms(50); led_set(0); Delay_Ms(50); }
    }
    pga_probe[0] = pga_probe_read(3, 0);
    pga_probe[1] = pga_probe_read(3, 1);
    pga_probe[2] = pga_probe_read(1, 0);
    pga_probe[3] = pga_probe_read(1, 1);
    pga_probe_done = 1;
    while (1)                              /* slow blink: results ready */
    {
        led_set(1); Delay_Ms(500);
        led_set(0); Delay_Ms(500);
    }
}
#elif DRIVER_PIN_TEST == 2
/* Frozen six-step states through motor_debug_outputs(): the control loop
 * state machine is bypassed, only TIM1 registers are written. With
 * DRIVER_PIN_TEST_HOLD = 0 the six steps are applied in order, one every
 * DRIVER_PIN_TEST_STEP_MS; the LED blinks (step + 1) times at each change.
 * With HOLD = N the probe stays on six-step entry N - 1. */
volatile int32_t  step_lsb[6];          /* mean shunt reading per six-step entry, LSB */
volatile uint16_t step_boff[6];         /* floating phase, OFF time, raw LSB (0 V expected at standstill) */
volatile int16_t  step_bon[6];          /* floating phase, in the pulse, minus Vbus/2 (0 expected) */
volatile int32_t  step_ma[6];           /* same in mA */
volatile int32_t  probe_zero;
volatile uint8_t  probe_steps_done;
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
int main(void)
{
    uint8_t  armed = 0;
    uint8_t  cells = 0;
    uint32_t arm_start_ms = 0;
    (void)arm_start_ms;
    uint32_t last_ms = 0, last_tel_ms = 0, last_ntc_ms = 0;
    int16_t  temp_c = 25;
    uint16_t vlimit = 1000, tlimit = 1000;

    /* why the chip restarted (debugger): RCC RSTSCKR bits 31..24,
     * 0x04 reset pin / debugger, 0x08 power-on or brown-out, 0x10 software,
     * 0x20 independent watchdog, 0x40 window watchdog */
    reset_cause = (uint8_t)(RCC->RSTSCKR >> 24);
    RCC_ClearFlag();
    run_log_boot(reset_cause);

    NVIC_PriorityGroupConfig(NVIC_PriorityGroup_1);
    SystemCoreClockUpdate();
    Delay_Init();

    led_init();
    led_set(1);
    tel_init();
#if DRIVER_PIN_TEST == 6
    ls_tim1_test();               /* never returns, low sides only */
#elif DRIVER_PIN_TEST == 5
    hs_check();                   /* never returns, bridge off after 32 s */
#elif DRIVER_PIN_TEST == 4
    current_sweep();              /* never returns, bridge off after ~1.5 s */
#elif DRIVER_PIN_TEST == 3
    pga_path_test();              /* never returns, bridge never enabled */
#elif DRIVER_PIN_TEST == 2
    driver_tim1_test();           /* never returns */
#elif DRIVER_PIN_TEST == 1
    driver_pin_test();            /* never returns */
#endif
    if (motor_init())             /* starts the control loop, calibrates the shunt offset */
    {
        /* Control loop never ran: blink fast forever, never arm. */
        tel_puts("\r\nFATAL: control loop not running (ADC/TIM1)\r\n");
        while (1)
        {
            led_set(1); Delay_Ms(50);
            led_set(0); Delay_Ms(50);
        }
    }
    motor_set_direction(MOTOR_REVERSE);

    PLAY(mel_power);

    /* Auto-detection of the connected motor (see motor_tune.h). */
#if AUTOTUNE_MODE == 2
    PLAY(mel_tune);
    run_now.phase = 2;
        (void)tune_run(tune_led);
    if (tune_res.status == TUNE_OK) PLAY(mel_tune_ok); else PLAY(mel_fail);
#elif AUTOTUNE_MODE == 1
    if (!tune_load())
    {
        PLAY(mel_tune);
        run_now.phase = 2;
        (void)tune_run(tune_led);
        if (tune_res.status == TUNE_OK) PLAY(mel_tune_ok); else PLAY(mel_fail);
    }
#else
    (void)tune_load();
#endif
    if (tune_res.status != TUNE_OK)
    {
        /* tune failed or absent: defaults stay in use; show the code for 3 s
         * (status number = short blinks) */
        uint8_t k, b;
        for (k = 0; k < 2U && tune_res.status > TUNE_OK; k++)
        {
            for (b = 0; b < (uint8_t)tune_res.status; b++)
            {
                led_set(1); Delay_Ms(150);
                led_set(0); Delay_Ms(250);
            }
            Delay_Ms(1000);
        }
    }
    run_now.tune_status     = (uint8_t)tune_res.status;
    run_now.tune_stop_fault = tune_res.stop_fault;
    run_now.phase           = 3;
    rc_init();
    iwdg_init();
    led_set(0);

    tel_puts("\r\nCogless ESC, CH32M007G8R6, sysclk=");
    tel_put_uint(SystemCoreClock);
    tel_puts("\r\n");

#if TEST_AUTORUN
    /* the test schedule starts here, after the melodies and the auto-tune,
     * not at power-up */
    const uint32_t run_t0 = motor_millis();
    /* the test only starts after a real power-up: a debugger (re)connection
     * resets the chip without power-cycling it, the motor then stays still
     * and run_prev keeps the results of the last run */
    const uint8_t autorun_ok = (uint8_t)((reset_cause & 0x08U) != 0U);
#endif
    while (1)
    {
        uint32_t      now = motor_millis();
        uint16_t      thr;
        uint8_t       rc_ok;
        motor_state_t st;
        motor_fault_t f;

        if (now == last_ms)
        {
            continue;             /* 1 ms scheduler */
        }
        last_ms = now;
        IWDG_ReloadCounter();

#if TEST_AUTORUN
        /* Self-running test: throttle schedule instead of the RC input. */
        rc_ok = 1;
        if (!autorun_ok)
        {
            rc_ok = 0;                 /* hold: one long blink every 2 s */
            thr   = 0;
        }
        else if (now - run_t0 < TEST_AUTORUN_DELAY_MS)
        {
            thr = 0;
        }
        else
        {
#if LONG_TEST
            thr = long_test_step(now - run_t0 - TEST_AUTORUN_DELAY_MS, temp_c);
#else
            /* Staircase: first level lasts longer to cover the start-up, then
             * one level every TEST_LEVEL_MS, then TEST_AUTORUN_OFF_MS stopped.
             * The state at the end of each level is stored in run_now.level[]. */
            static const uint16_t levels[TEST_LEVELS_N] = TEST_LEVELS;
            const uint32_t on_ms = TEST_LEVEL0_EXTRA_MS + TEST_LEVELS_N * TEST_LEVEL_MS;
            uint32_t t = (now - run_t0 - TEST_AUTORUN_DELAY_MS) % (on_ms + TEST_AUTORUN_OFF_MS);
            int8_t   li;

            if (TEST_AUTORUN_ONCE && (now - run_t0 - TEST_AUTORUN_DELAY_MS) >= on_ms)
            {
                t = on_ms;                     /* played once: stay stopped */
            }
            if (t >= on_ms)
            {
                li  = -1;
                thr = 0;
                if (run_now.phase == 4 && motor_state() != MOTOR_RUN && motor_state() != MOTOR_RAMP) { run_now.phase = 5; run_log_counters(); run_log_save(&run_now); }
            }
            else
            {
                li = (t < TEST_LEVEL0_EXTRA_MS) ? 0
                     : (int8_t)((t - TEST_LEVEL0_EXTRA_MS) / TEST_LEVEL_MS);
                thr = levels[li];
                run_now.phase = 4;
            }
            if (li != level_prev)
            {
                if (level_prev >= 0)
                {
                    volatile level_log_t *e = &run_now.level[level_prev];
                    e->thr     = levels[level_prev];
                    e->duty_pm = motor_duty();
                    e->erpm    = motor_erpm();
                    e->rpm     = motor_erpm() / TEST_MOTOR_POLE_PAIRS;
                    e->i_ma    = motor_current_ma();
                    e->vbus_mv = motor_vbus_mv();
                    e->state   = (uint8_t)motor_state();
                    e->fault   = (uint8_t)motor_fault();
                    e->i_avg_ma    = lv_n ? (int32_t)(lv_sum_i / (int64_t)lv_n) : 0;
                    e->ibat_ma     = lv_n ? (int32_t)(lv_sum_ibat / (int64_t)lv_n) : 0;
                    e->i_peak_ma   = lv_peak;
                    e->vbus_min_mv = lv_vmin;
                    e->peak_hits   = (uint16_t)(motor_peak_hits() - lv_hits0);
                    e->temp_max_c  = lv_tmax;
                    e->fold_max_pm = motor_fold_max_pm();
                    {
                        uint16_t zr, ze, zb;
                        motor_zc_counts(&zr, &ze, &zb);
                        e->zc_real  = (uint16_t)(zr - lv_zr0);
                        e->zc_early = (uint16_t)(ze - lv_ze0);
                        e->zc_blind = (uint16_t)(zb - lv_zb0);
                    }
                }
                lv_sum_i = 0; lv_sum_ibat = 0; lv_n = 0; lv_peak = 0;
                lv_vmin  = 0xFFFF;
                lv_tmax  = -100;
                lv_hits0 = motor_peak_hits();
                motor_zc_counts(&lv_zr0, &lv_ze0, &lv_zb0);
                (void)motor_fold_max_pm();
                if (li == 0)
                {
                    uint8_t k;
                    for (k = 0; k < TEST_LEVELS_N; k++) run_now.level[k].thr = 0;
                }
                level_prev = li;
            }
            if (li >= 0)
            {
                /* per-level statistics, once per ms */
                int32_t  i = motor_current_ma();
                uint16_t v = motor_vbus_mv();
                lv_sum_i    += i;
                lv_sum_ibat += (int64_t)i * motor_duty() / 1000;
                lv_n++;
                if (i > lv_peak) lv_peak = i;
                if (v < lv_vmin) lv_vmin = v;
                if (temp_c > lv_tmax) lv_tmax = temp_c;
            }
#endif
        }
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

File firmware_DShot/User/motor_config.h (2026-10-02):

/* SPDX-License-Identifier: GPL-3.0-only OR LicenseRef-Cogless-Commercial
 * Copyright (c) 2026 Ronan Mingon */
/*
 * motor_config.h - tunable parameters of the sensorless six-step controller.
 * Hardware facts (pins, dividers, shunt) live in board.h.
 */
#ifndef MOTOR_CONFIG_H
#define MOTOR_CONFIG_H

#include "board.h"

/* ------------------------------------------------------------------ PWM */
#define PWM_FREQ_HZ              32000U   /* 24000 or 48000 */
/* centre-aligned: 0 -> ARR -> 0 in one PWM period */
#define PWM_PERIOD_TICKS         (BOARD_TIM1_CLK_HZ / (2U * PWM_FREQ_HZ))
/* OFF time needed after the top for the BEMF sample: interrupt latency
 * ~47 ticks + sampling ~23 + margin. At 48 kHz it limits the duty to ~83 %. */
#define PWM_OFF_SAMPLE_TICKS     85U
#define PWM_DUTY_MAX_90          (PWM_PERIOD_TICKS * 90U / 100U)   /* bootstrap refresh */
#define PWM_DUTY_MAX             (((PWM_PERIOD_TICKS - PWM_OFF_SAMPLE_TICKS) < PWM_DUTY_MAX_90) \
                                  ? (PWM_PERIOD_TICKS - PWM_OFF_SAMPLE_TICKS) : PWM_DUTY_MAX_90)
#define PWM_DUTY_MIN             (PWM_PERIOD_TICKS * 3U / 100U)
#define PWM_DEAD_TIME_NS         400U
#define PWM_DEAD_TIME_TICKS      ((PWM_DEAD_TIME_NS * (BOARD_TIM1_CLK_HZ / 1000000U)) / 1000U)
/* hardware ADC trigger (ADC_TRIGGER_HW 1): TIM1 CH4 compare before the bottom */
#define PWM_ADC_TRIGGER_TICKS    17U
/* 1: TIM1 CC4 event triggers the ADC, control loop in the ADC interrupt
 * 0: TIM1 CC4 interrupt starts the ADC by software, then runs the loop */
#define ADC_TRIGGER_HW           0
/* software trigger: JSWSTART lands ~47 ticks after the CC4 match, the shunt
 * sample holds ~23 ticks later, i.e. ~15 ticks after the bottom, away from
 * the high-side turn-on transient */
#define PWM_ADC_TRIGGER_TICKS_SW 55U
/* interrupt waits are bounded by the timer, not by a loop count:
 * injected sequence: done ~160 ticks after the bottom, abandoned past this */
#define CC_WAIT_MAX_TICKS        320U
/* OFF-time conversion: done ~70 ticks after the top, abandoned past this */
#define UP_WAIT_MAX_TICKS        200U
/* ADC start later than this past the bottom: current sample ignored */
#define SAMPLE_LATE_TICKS        15U
/* this many late samples in a row with the bridge on: fault (the current
 * would otherwise go unmeasured) */
#define LATE_RUN_MAX             16U
/* 1: one motor_trace entry per closed-loop commutation (debug, costs CPU
 * time at 48 kHz); 0: open-loop start only, zc_stat counts in closed loop */
#define TRACE_IN_RUN             0
/* more than OVR_WINDOW_MAX lost control ticks within OVR_WINDOW_TICKS
 * (power of two, ~85 ms at 48 kHz) with the bridge on: overrun fault */
#define OVR_WINDOW_TICKS         4096U
#define OVR_WINDOW_MAX           32U

/* control loop tick = one PWM period */
#define CTRL_TICK_HZ             PWM_FREQ_HZ
/* Constants tuned at 24 kHz (1000 ticks per period) and written in control
 * ticks are scaled to the actual frequency, so any PWM_FREQ_HZ works
 * (24, 32, 48 kHz...). TICKS_24K(n) = n ticks of the 24 kHz loop. */
#define TICKS_24K(n)             (((uint32_t)(n) * CTRL_TICK_HZ + 12000U) / 24000U)
/* "one duty tick every N control ticks" rates: the loop runs CTRL_TICK_HZ /
 * 24000 times faster AND a duty tick is 1000 / PWM_PERIOD_TICKS times
 * larger. N is multiplied by this ratio, rounded to a power of two (1, 2,
 * 4: it is used as a bit mask). 24 kHz: 1, 32 kHz: 2, 48 kHz: 4. */
#define DUTY_RATE_RATIO_X10      ((CTRL_TICK_HZ * 10000U / PWM_PERIOD_TICKS) / 24000U)
#define DUTY_RATE_SCALE          ((DUTY_RATE_RATIO_X10 >= 30U) ? 4U : (DUTY_RATE_RATIO_X10 >= 15U) ? 2U : 1U)
#define MS_TO_TICKS(ms)          ((uint32_t)(ms) * CTRL_TICK_HZ / 1000U)
/* 100 us units keep multi-second values inside 32 bits */
#define US_TO_TICKS(us)          (((uint32_t)(us) / 100U) * (CTRL_TICK_HZ / 100U) / 100U)

/* ---------------------------------------------------------- bench tests
 * MOTOR_TEST_OPEN_LOOP 1: forced commutation forever after the alignment,
 * no zero-crossing detection. Validates the power stage and the step table. */
#define MOTOR_TEST_OPEN_LOOP     0
#define RAMP_TEST_STEP_US        20000U
#define RAMP_TEST_START_US       100000U
#define RAMP_TEST_DUTY_PCT       3U
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

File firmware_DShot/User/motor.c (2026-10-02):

/* SPDX-License-Identifier: GPL-3.0-only OR LicenseRef-Cogless-Commercial
 * Copyright (c) 2026 Ronan Mingon */
/*
 * motor.c - sensorless six-step BLDC controller, see motor.h.
 */
#include "motor.h"

/* Interrupt-path code runs from RAM: the flash needs 2 wait states at
 * 48 MHz, which the 48 kHz loop cannot afford. The startup code copies
 * .data (and so .data.ramfunc) from flash to RAM. */
#define RAMFUNC __attribute__((section(".data.ramfunc")))
#include "motor_config.h"
#include "debug.h"

/* ------------------------------------------------------------------ TIM1
 * Register images written on every commutation. Writing the three registers
 * directly is much faster than the library helpers and avoids intermediate
 * states. Channels: U = CH1, V = CH2, W = CH3, CH4 = ADC trigger only.
 */
#define OCM_PWM1          0x0060U   /* OCxM = 110b, PWM mode 1                  */
#define OCM_FORCED_LOW    0x0040U   /* OCxM = 100b, OCx inactive -> OCxN active */
#define OCM_FORCED_HIGH   0x0050U   /* OCxM = 101b, only used for a sub-dead-time edge */
#define OCM_MASK          0x0070U
#define OC_PRELOAD        0x0008U

typedef struct
{
    uint16_t chctlr1;       /* CH1 / CH2 mode  */
    uint16_t chctlr2;       /* CH3 / CH4 mode  */
    uint16_t ccer;          /* output enables  */
    uint16_t chctlr1_edge;  /* same, low-side channels forced ACTIVE (edge maker) */
    uint16_t chctlr2_edge;
} out_regs_t;

enum { PH_U = 0, PH_V = 1, PH_W = 2, PH_NONE = 3 };

/* step -> { PWM (high side) phase, low-side phase, floating phase } */
static const uint8_t step_table[6][3] =
{
    { PH_U, PH_V, PH_W },
    { PH_U, PH_W, PH_V },
    { PH_V, PH_W, PH_U },
    { PH_V, PH_U, PH_W },
    { PH_W, PH_U, PH_V },
    { PH_W, PH_V, PH_U },
};

static const uint16_t ccer_phase[3] =
{
    TIM_CC1E | TIM_CC1NE,
    TIM_CC2E | TIM_CC2NE,
    TIM_CC3E | TIM_CC3NE,
};

/* A phase that is off must still have its two driver inputs DRIVEN low.
 * With CCxE = CCxNE = 0 TIM1 releases both pins (not driven, RM OSSR note)
 * and the gate driver sees floating HIN/LIN inputs. Keeping CCxE = 1 with
 * OCxREF forced inactive drives OCx = 0, and OSSR = 1 drives OCxN at its
 * inactive level (0). */
static const uint16_t ccer_off[3] =
{
    TIM_CC1E,
    TIM_CC2E,
    TIM_CC3E,
};

static const uint8_t bemf_adc_ch[3] =
{
    BOARD_BEMF_U_ADC_CH, BOARD_BEMF_V_ADC_CH, BOARD_BEMF_W_ADC_CH,
};

static out_regs_t step_regs[6];
static out_regs_t regs_brake;
static out_regs_t regs_low_only[3];   /* one low side forced on, nothing else */
static out_regs_t regs_off;
static uint32_t   isqr_for_phase[3];

/* ---------------------------------------------------------------- state */
typedef struct
{
    volatile motor_state_t state;
    volatile motor_fault_t fault;
    volatile uint32_t fault_ms;

    /* time */
    volatile uint32_t tick;
    volatile uint32_t ms;
    uint16_t          ms_acc;
    uint32_t          state_ticks;

    /* commutation */
    uint8_t  step;
    uint8_t  reverse;
    uint32_t step_ticks;      /* ticks since last commutation             */
    uint32_t zc_ticks;        /* ticks since last zero crossing           */
    uint32_t zc_period;       /* filtered 60 deg period, ticks            */
    uint32_t zc_period_x16;   /* same with 4 fractional bits (closed loop) */
    uint8_t  zc_missed;       /* consecutive steps without a crossing      */
    uint8_t  speed_capped;    /* 1 = at the speed ceiling                  */
    uint16_t cap_duty;        /* duty ceiling from the speed governor, 0 = none */
    uint16_t peak_hits;       /* cycle-by-cycle limit activations (diagnostic) */
    uint16_t zc_real_cnt;     /* closed loop: crossings seen happening (diagnostic) */
    uint16_t zc_early_cnt;    /* closed loop: "already crossed" crossings */
    uint16_t zc_blind_cnt;    /* closed loop: blind commutations */
    uint8_t  zc_kind;         /* trace flag of the crossing of this step: 0 real, 0x10 early */
    uint16_t cc_isr_max;      /* longest control interrupt, timer ticks from the CC4 match */
    uint16_t cc_overrun;      /* control interrupts still running at the next CC4 (tick lost) */
    uint16_t cc_late;         /* control interrupts entered late: current sample ignored */
    uint8_t  sample_late;     /* this tick's injected samples were not taken at the bottom */
    uint8_t  late_run;        /* consecutive late samples */
    volatile uint8_t ovr_win; /* lost ticks in the current OVR_WINDOW_TICKS window */
    uint8_t  sag_count;       /* consecutive bus samples below VBUS_SAG_FAULT_MV */
    int32_t  fault_i_raw;     /* shunt sample (LSB, 39.4 mA) when the last fault was raised */
    uint8_t  fault_state;     /* motor_state_t when the last fault was raised */
    uint16_t fault_duty;      /* duty (PWM ticks) when the last fault was raised */
    uint16_t i_fold_max;      /* largest fold-back since the last read (diagnostic) */
    uint8_t  start_phase;     /* 1 = direct start, no zero crossing seen yet */
    uint16_t beep_half;       /* ticks per half tone period */
    uint16_t beep_cnt;
    uint32_t beep_left;       /* ticks of tone remaining */
    uint8_t  beep_pol;
    uint16_t beep_pre;        /* bootstrap precharge ticks left before the tone */
    motor_start_cfg_t cfg;    /* start-up parameters (auto-tune or defaults) */
    uint32_t ramp_timeout;    /* ticks, from the configured ramp */
    int32_t  i_start_lsb;
    uint32_t commutate_at;    /* step_ticks value of the next commutation */
    uint8_t  zc_found;
    uint8_t  zc_armed;        /* sample seen on the "wrong" side first    */
    uint8_t  zc_first;        /* next ZC check is the first after blanking */
    volatile uint16_t bemf_off; /* floating phase sampled mid OFF time (raw LSB) */
    volatile uint16_t bemf_on;  /* floating phase sampled in the high-side pulse (raw LSB) */
    volatile uint8_t  bemf_ch_ok; /* regular group points at a BEMF channel (a step is applied) */
    uint16_t ntc_last;
    volatile uint8_t  ntc_req;  /* main asks for an NTC conversion in the OFF-time interrupt */
    uint8_t  good_zc;
    uint32_t ramp_period;

    /* duty */
    uint16_t throttle;        /* 0..1000 from main                        */
    uint16_t duty_limit;      /* 0..1000 from main (derating)             */
    uint16_t duty_target;     /* ticks                                    */
    uint16_t duty;            /* ticks, after slew                        */
    uint16_t i_fold;          /* ticks removed by the current limiter     */
    uint16_t slew_acc;
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

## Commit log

2026-08-14 first commit hardware
    [hardware.kicad_pcb, hardware.kicad_sch]
2026-08-14 use AOD514 instead AON6400
    [hardware.kicad_pcb, hardware.kicad_sch]
2026-08-14 add shunt A- + led + ntc
    [hardware.kicad_pcb, hardware.kicad_sch]
2026-08-15 first pcb position
    [hardware.kicad_pcb, hardware.kicad_sch]
2026-08-15 fix mosfet postion
    [hardware.kicad_pcb]
2026-08-15 finish pcb wiring + change batt+ capacitors
    [hardware.kicad_pcb, hardware.kicad_sch]
2026-08-16 add revision + finish PCB
    [hardware.kicad_pcb, hardware.kicad_sch]
2026-10-02 firmware_DShot: MounRiver project with the WCH CH32V00X SDK
    CH32M007G8R6 target, RV32EC, -msave-restore off (interrupt code runs
    from RAM). Link.ld reserves the last 768 B of flash for the run log and
    the auto-tune record and adds a .noinit section that survives resets.
    Build output and MounRiver workspace state are ignored.
2026-10-02 firmware_DShot: board definition for the Cogless ESC
    Pin map from hardware.kicad_sch (TIM1 remap 4 to the internal gate
    driver, PGA on the 2 mohm shunt, BEMF and battery dividers, NTC, LED,
    RC input on PA1) and the ADC scaling factors derived from it.
2026-10-02 firmware_DShot: non-blocking SDI telemetry
    Text output over the WCH-Link debug mailbox that gives up after ~1 ms
    when nobody reads it, so the ESC runs the same with or without a
    debugger (the stock printf blocks forever).
2026-10-02 firmware_DShot: servo PWM throttle input on PA1
    EXTI on both edges time-stamped by TIM2 as a free 1 MHz counter. No
    TIM2 remap: remaps 5/6 would take PA0/PA2/PA3 from the gate driver.
    Pulse window 800..2300 us, 100 ms failsafe timeout.
    [rc_input.c]
2026-10-02 firmware_DShot: sensorless six-step motor controller
    Control loop at the PWM rate in the TIM1 interrupts, code in RAM:
    shunt current through the PGA, bus voltage, floating-phase BEMF in the
    PWM OFF time, zero-crossing commutation with current-regulated
    open-loop start, duty slew, current fold-back, speed governor, faults.
    CMP2 -> TIM1 break kept enabled as the hardware over-current.
    Off phases keep CCxE = 1 with the output forced inactive so the driver
    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
2026-10-02 firmware_DShot: motor auto-detection stored in flash
    Standstill duty/current sweep, parasitic floor, open-loop acceleration
    checked with BEMF peak x period, hand-off speed. Result written at
    0x0800F700 and reloaded at power-up.
2026-10-02 firmware_DShot: main loop
    Power-up beeps, auto-tune, 1 ms scheduler: arming, voltage and
    temperature derating, LED patterns, telemetry, watchdog. Run log in
    .noinit copied to flash on faults (post-mortem without a debugger).
    Bench probes (DRIVER_PIN_TEST), autorun and long test switches.
2026-10-02 firmware_DShot: README
    Architecture, start-up sequence, auto-tune, bring-up findings, test
    switches, command-line build recipe, licence.
2026-10-02 Switch to copyleft licences and add a commercial licence notice
    Firmware: MIT -> GPL-3.0-only. Hardware: CERN-OHL-P v2 -> CERN-OHL-S v2.
    LICENSE-COMMERCIAL.md explains when a commercial licence is needed and
    what it covers; the WCH SDK files stay under WCH's own terms.
2026-10-02 README: rewrite for the first prototype
    Specifications, design notes, firmware feature and protection tables,
    current limitations, getting started, repository layout, safety, and the
    dual-licence terms. Firmware folder is now firmware_DShot/.
